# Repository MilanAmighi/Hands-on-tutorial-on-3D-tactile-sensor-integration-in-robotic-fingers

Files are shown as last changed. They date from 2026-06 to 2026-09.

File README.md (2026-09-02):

# 🤖 Hands-on Tutorial: 3D Tactile Sensor Integration in Robotic Fingers for Smart Manipulation

**Hands-on Tutorial presented at ICRA 2026**

**Organisers of the event:** Milan Amighi, Constantin Scholz, and Bram Vanderborght  
*(Brubotics – VUB & imec, in collaboration with Melexis)*

---

## 🧠 Overview

Despite skin being our largest sensory organ, touch remains underused in robotics. Tactile sensing is vital for safe and dexterous manipulation, human-robot interaction, and wearable devices, yet most robotic sensors measure only normal pressure. We live among materials with distinct rigidity, friction, weight, and texture, differences that humans intuitively perceive through touch. Robots can already move, see, and hear; the next frontier is enabling them to truly *feel*, so they can grasp delicate and deformable objects while accounting for each object's physical properties.

This hands-on tutorial introduces an affordable, compact, and robust 3D tactile sensor developed by Melexis: the **Tactaxis® 3D force sensor**, which uses automotive-grade Hall-effect technology to measure both normal and shear forces simultaneously.

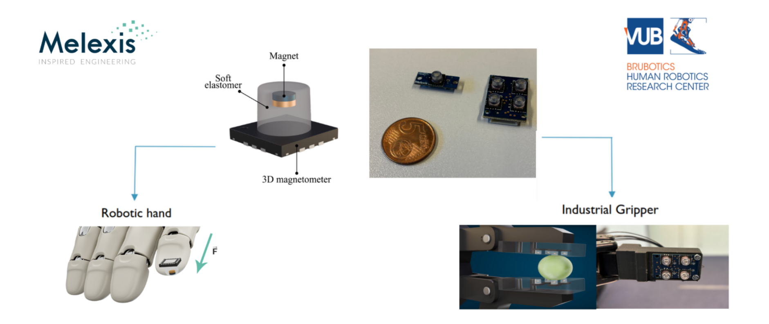
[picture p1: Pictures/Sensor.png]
Melexis Tactaxis 3D Force Sensor


<p align="center">
  Touch sensor demo
</p>

This tutorial allows the user to:
- 🔩 Assemble a two-finger gripper ([PincOpen from Pollen Robotics](https://pollen-robotics.github.io/PincOpen/))
- 🖐️ Integrate the Tactaxis® sensor into the fingertips
- 🚀 Deploy the full system on a real robotic manipulation task

Through guided experiments, you will map force signals to interaction dynamics, detect slip, and implement adaptive grasp control that responds to the properties of the object being handled. You will leave with practical know-how, open-source resources, and a grounded understanding of why touch enables safer, more precise, and more versatile robot behavior.

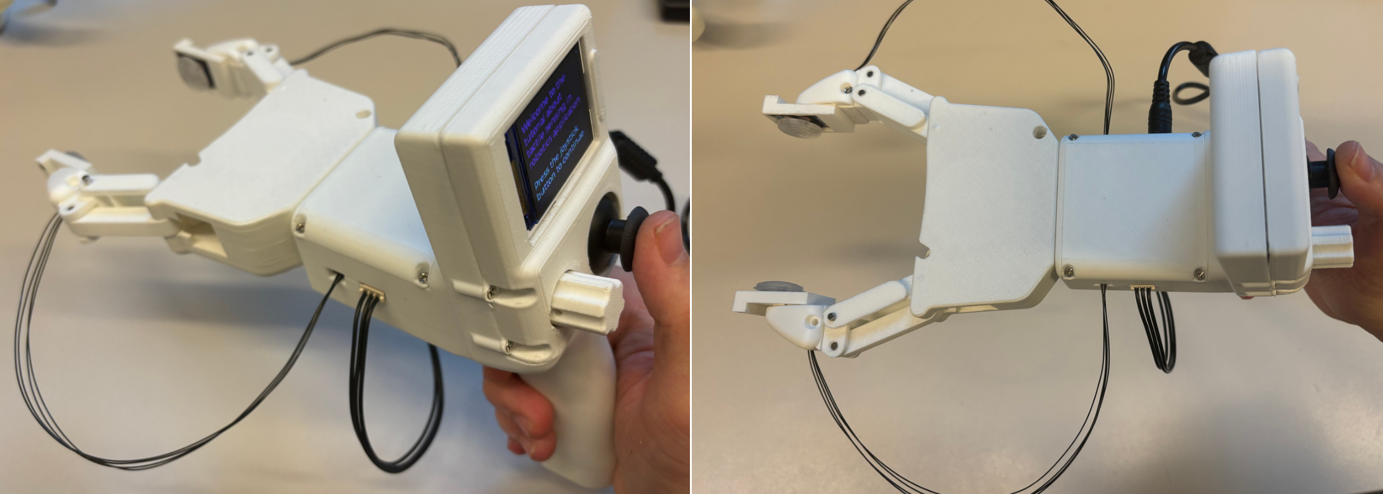
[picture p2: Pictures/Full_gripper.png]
Full gripper overview


**Small video of workshop/tutorial presented at ICRA2026:** [▶️ Watch on YouTube](https://www.youtube.com/watch?v=7zQnEL_h0f4)

**Concept demonstration on a Robotiq 2F-85 gripper(ITF 2025 with imec):** [▶️ Watch on YouTube](https://www.youtube.com/watch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)

---

## 📁 Repository Structure

```
.
├── Gripper-BOM.xlsx                  # Bill of materials: electronics, fasteners, and parts needed to build the gripper, with purchase links
├── Gripper Kit - Assembly guide.pdf  # Step-by-step assembly guide for the full gripper
├── Electronics/                      # Circuit diagrams and electronics documentation
├── Design/                           # STEP and STL files for 3D printing, incl. the moulds for the PDMS sensor cover
├── Docker/                           # Dockerfile and scripts to create a containerised ROS 2 environment
├── Codes/                            # ROS 2 packages, python only and motor initialisation scripts
├── pyproject.toml                    # Pixi environment (ROS 2 via RoboStack) + Python dependencies + `pixi run` tasks
├── pixi.lock                         # Reproducible Pixi environment
├── requirements.txt                  # Minimal pip dependencies for the Python-only scripts
```

---

## ✅ Prerequisites

- Basic familiarity with ROS 2 and Python is helpful but not required
- One of the three environments below (Pixi, Docker, or a manual install) installed on your laptop
- All hardware kits (3D-printed parts, fasteners, sensors) will be provided on-site

---

## 🏁 Getting Started

> The following code has been tested on Ubuntu 22.04. A Dockerfile and Pixi environment are also provided to automatically install all required libraries, depending on the OS used by the user. 

### Step 1 — Clone the repository

```bash
git clone https://github.com/MilanAmighi/Hands-on-tutorial-on-3D-tactile-sensor-integration-in-robotic-fingers.git
cd Hands-on-tutorial-on-3D-tactile-sensor-integration-in-robotic-fingers
```

> ⚠️ **Windows users — long paths warning.** This repository contains deeply nested files. You **must** enable long paths in Git *before* cloning, or your checkout will fail:
>
> ```bash
> git config --global core.longpaths true
> ```

### Step 2 — Assemble the gripper

Follow `Gripper Kit - Assembly guide.pdf` to build the complete gripper. The list of material is in `Gripper-BOM.xlsx`, all the CAD design in the folder `Design` and the PCB schematics in the folder `Electronics`.

### Step 3 — Install your software environment

Three options are provided. **You only need one of them**; pick the one matching your operating system and preference:

| Option | Best for | OS | ROS 2 included | 
|---|---|---|---|
| **A. 🧪 Pixi** *(recommended)* | Everyone, especially MacOS and Windows | MacOS (Intel & Apple Silicon), Linux, Windows | ✅ Humble via RoboStack | 
| **B. 🐳 Docker** | Linux users who prefer containers | Ubuntu 22.04 (tested) | ✅ Humble | 
| **C. 🐍 Manual install** | Quick sensor tests without ROS 2 | Windows, Linux, MacOS | ❌ (install it yourself) | 

---

## 🧪 Option A — Pixi

[Pixi](https://pixi.prefix.dev/latest/) automatically manages ROS 2 and Python dependencies locally on **Windows, Linux and MacOS**, without needing a full virtual machine or a Docker container. ROS 2 Humble comes from [RoboStack](https://robostack.github.io) and everything is pinned in `pixi.lock`, so every participant gets the exact same environment.

**A.1 — Install Pixi** (if you haven't already):

- Windows (PowerShell):
  ```powershell
  iwr -useb https://pixi.sh/install.ps1 | iex
  ```
- Linux/MacOS (Bash):
  ```bash
  curl -fsSL https://pixi.sh/install.sh | bash
  ```

Restart your terminal after installing, then verify:

```bash
pixi --version
```

**A.2 — Set up the environment**, from the root of the repository:

```bash
cd Hands-on-tutorial-on-3D-tactile-sensor-integration-in-robotic-fingers
pixi install  # Downloads all ROS 2 and Python dependencies
pixi shell    # Activates the isolated environment
```

The first `pixi install` downloads ROS 2 Humble and all Python dependencies into a local `.pixi/` folder and can take several minutes.

**A.3 — Build the workspace:**

```bash
pixi run build
```

**A.4 — Run tasks.** List them with:

```bash
pixi task list
```

Then run one with:

```bash
pixi run <name-of-the-task>
```

Multible task and codes are available in `/Hands-on-tutorial-on-3D-tactile-sensor-integration-in-robotic-fingers/Codes`.

---

## 🐳 Option B — Docker

The Dockerfile builds an Ubuntu 22.04 image with ROS 2 Humble and all Python dependencies pre-installed. Tested on Ubuntu 22.04 hosts.

> ⚠️ **Plug the USB-C cable in before starting the container.** Serial devices are mapped at container start; a cable plugged in afterwards will not be visible inside the container.

**B.1 — Install Docker** ([official guide](https://docs.docker.com/engine/install/)) and allow your user to run it:

```bash
sudo usermod -aG docker $USER    # then log out and back in
docker run hello-world
```

**B.2 — Build the image and start the container**, from the `Docker/` folder. **Before starting the Docker container**, connect the USB-C cable from the gripper to your computer:

```bash
cd Docker
./buildrun.sh
```

`buildrun.sh` runs `build.sh` (builds the `docker3dsensors` image) followed by `run.sh` (starts the container with the serial devices, USB bus and X11 display forwarded, and the repository mounted at `/Hands-on-tutorial-on-3D-tactile-sensor-integration-in-robotic-fingers`).

**B.3 — Open extra terminals** in the *same running* container (some demos need two):

```bash
docker exec -it docker3dsensors bash
```

**B.4 — Build the ROS 2 workspace**, inside the container:

```bash
cd /Hands-on-tutorial-on-3D-tactile-sensor-integration-in-robotic-fingers/Codes/ros2_ws
colcon build
source install/setup.bash
```

---

## 🐍 Option C — Manual/native install

Use this if you only want the Python scripts without ROS 2.

**C.1 — Install Python 3** (3.12 or newer recommended).

**C.2 — Install the Python dependencies**, from the root of the repository:

```bash
pip install -r requirements.txt
```

`requirements.txt` contains `numpy`, `pyserial`, `crc` and `esptool` — enough for `flash.py`, `Motor_initialisation.py`, `simple_connected_mode.py` and `BurstMode.py`.

**C.3 — (Optional) Install ROS 2 Humble yourself** if you also want the ROS 2 nodes, via the [official installation guide](https://docs.ros.org/en/humble/Installation.html), then build the workspace:

```bash
cd Codes/ros2_ws
colcon build
source install/setup.bash
```

> On Windows, replace `/` with `\` in the paths and use `python` instead of `python3`.

---

## ▶️ Next: running the code

Once your environment is installed and the gripper is assembled, connect the ESP32-S3 by USB-C, set the gripper LCD to **Connected** mode, and follow [`Codes/README.md`](Codes/README.md). It covers, for each of the three environments:

- 🔥 flashing the ESP32 firmware,
- ⚙️ initialising the motor before mounting it on the gripper,
- 🕹️ the gripper operating modes (independent, connected, view forces),
- 📡 the Python-only scripts and the ROS 2 demos (tactile visualisation, full system + RViz, PID force control),
- 💾 the CSV recording format and the ROS 2 topic list.

---

## 🙏 Acknowledgements

This project was made possible with the support of **VLAIO** under the Skinaxis project and the **euRobin EU project**. We would also like to sincerely thank:
- **Melexis**, for making this tutorial possible by providing the Tactaxis® sensors
- **ICRA organisers**, for the opportunity to present to the robotics community
- **Pollen Robotics**, for supporting the project with the PincOpen gripper platform

---

## 📬 Contact

| Organisation | Contact |
|---|---|
| Brubotics (VUB & imec) | [Milan.Francois.T.Amighi@vub.be](mailto:Milan.Francois.T.Amighi@vub.be) |
| Melexis | [tls@melexis.com](mailto:tls@melexis.com) |

---

## 📚 References

- T. Le Signor, N. Dupré and G. F. Close, "A Gradiometric Magnetic Force Sensor Immune to Stray Magnetic Fields for Robotic Hands and Grippers," *IEEE Robotics and Automation Letters*, vol. 7, no. 2, pp. 3070–3076, April 2022. [doi:10.1109/LRA.2022.3146507](https://doi.org/10.1109/LRA.2022.3146507)

- T. Le Signor, N. Dupré, J. Didden, E. Lomakin, G. Close, "Mass-Manufacturable 3D Magnetic Force Sensor for Robotic Grasping and Slip Detection," *Sensors*, 23, 3031, 2023. [doi:10.3390/s23063031](https://doi.org/10.3390/s23063031)

- PincOpen Gripper — Pollen Robotics: [https://pollen-robotics.github.io/PincOpen/](https://pollen-robotics.github.io/PincOpen/)

- Fischer, T., Vollprecht, W., Traversaro, S., Yen, S., Herrero, C., & Milford, M. (2021). A RoboStack Tutorial: Using the Robot Operating System Alongside the Conda and Jupyter Data Science Ecosystems. *IEEE Robotics and Automation Magazine*, 28(2). https://doi.org/10.1109/MRA.2021.3128367

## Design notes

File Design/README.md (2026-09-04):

# 🛠️ Design Files

This folder contains all STEP and STL files needed to 3D print and assemble the gripper used in this tutorial. Files are organised into two subfolders:

- 📐 **`step/`** — STEP files for editing or importing into CAD software
- 🧩 **`stl/`** — STL files ready for slicing and printing

---

## 🖨️ Printing Settings

All parts were printed using a **Bambu Lab H2D** printer with the following settings:

| Parameter | Value |
|---|---|
| Infill | 20% |
| Material | PLA (recommended) |

---

## 🧱 Components

### 📦 From the PincOpen Repository (unmodified)

These parts are sourced directly from the [Pollen Robotics PincOpen repository](https://github.com/pollen-robotics/PincOpen/tree/main/cad). Download them there, they are not duplicated here.

| Part | Quantity |
|---|---|
| Internal Rod | 2 |
| External Rod | 2 |
| Distal Rod | 2 |
| Top Plate | 1 |
| Motor Flange | 1 |
| Cam | 1 |
| Driving Rod | 2 |
| Bottom Plate | 1 |

---

### 🔧 Modified from PincOpen (adapted for Tactaxis® sensor integration)

These parts originate from the PincOpen design but have been modified to accommodate the Melexis Tactaxis® 3D force sensors in the fingertips.

| Part | Quantity |
|---|---|
| Removable Tip | 2 |
| Distal Shell | 2 |

---

### ✨ New Components (added for electronics integration)

These parts are fully original additions to the design, providing housing for the PCB and control electronics.

| Part | Quantity |
|---|---|
| Head Housing | 1 |
| Interface Panel for Head Housing | 1 |
| Top Panel for Head Housing | 1 |
| Potentiometer Knob | 1 |

---

### 🎯 Sensor Reference Model

A reference STEP and STL of the Tactaxis® sensor body is included for alignment and integration purposes.

| Part | Quantity |
|---|---|
| Tactaxis Sensor | 2 |

---

### 🫧 PDMS Sensor Cover (moulded)

A soft silicone cover sits on top of each Tactaxis® sensor to **distribute the contact force more evenly across the four taxels**, instead of letting a point contact load a single taxel. It is not 3D printed: it is cast in a two-part mould, which is printed.

| Part | Quantity | File |
|---|---|---|
| Tactaxis PDMS Cover *(cast, reference geometry)* | 2 | `stl/Tactaxis_PDMS_Cover.STL` · `step/Tactaxis_PDMS_Cover.STEP` |
| Cover Mould — Bottom | 1 | `stl/Tactaxis_PDMS_Cover_Mold_Bottom.STL` · `step/…_Mold_Bottom.STEP` |
| Cover Mould — Top | 1 | `stl/Tactaxis_PDMS_Cover_Mold_Top.STL` · `step/…_Mold_Top.STEP` |

**Material:** the covers are cast in **SYLGARD™ 182 Silicone Elastomer** from Dow, a two-part PDMS with a hardness of **Shore 43A**. Only the two mould halves are 3D printed; the `Tactaxis_PDMS_Cover` file itself is the resulting part geometry, provided as a reference for CAD and for checking the fit in the fingertip.

---

## 📡 Tactaxis® Sensor — Info & Dimensions

The **Melexis Tactaxis® 3D force sensor** is a compact, automotive-grade Hall-effect sensor that simultaneously measures normal (Fz) and shear (Fx, Fy) forces. It is designed for integration into robotic fingertips where space and robustness are critical.

| Dimensions | Value |
|---|---|
| Surface | ~24 mm × 18 mm |
| Overall assembly height | ~6 mm (sensor + magnet housing) |
| Number of taxels per sensor | 4 |

> The sensor snaps into the **Removable Tip** cavity. The STEP file `step/Tactaxis_Sensor.STEP` represents the sensor body and can be used as a reference when adapting the fingertip geometry.

---

## 📝 Notes

- The STEP files can be opened and modified in any CAD software (e.g. FreeCAD, Fusion 360, SolidWorks, OnShape).
- If you want to adapt the fingertip design for a different sensor, the **Removable Tip** and **Distal Shell** STEP files are the relevant starting points.
- For the full bill of materials including fasteners and electronics, refer to `BOM.xlsx` at the root of the repository.

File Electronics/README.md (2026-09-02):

# Electronics folder
Folder containing circuit diagrams and electronics documentation.

# ⚡ Electronics & Firmware
Welcome to the electronics section of the Tactile Sensor Gripper ! This folder contains everything you need to build the electronic circuit, understand the high-level firmware, and flash the code to your ESP32.

## 📋 Table of Contents
- [⚡ Electronics \& Firmware](#-electronics--firmware)
  - [📋 Table of Contents](#-table-of-contents)
  - [🔬 Overview](#-overview)
  - [🛠️ Hardware](#️-hardware)
    - [Bill of Materials (BOM)](#bill-of-materials-bom)
    - [Schematics](#schematics)
  - [🧠 Firmware Architecture](#-firmware-architecture)
    - [Mode 0 — Independent](#mode-0--independent)
    - [Mode 1 — Connected](#mode-1--connected)
    - [Serial Frame Protocol](#serial-frame-protocol)
      - [Frame structure](#frame-structure)
      - [Commands (PC → ESP32)](#commands-pc--esp32)
      - [Response (ESP32 → PC)](#response-esp32--pc)
      - [Burst frame payload (`0x15`) — 126 bytes total](#burst-frame-payload-0x15--126-bytes-total)
    - [Mode 2 — View Forces](#mode-2--view-forces)
  - [💻 Flashing the ESP32](#-flashing-the-esp32)
    - [Prerequisites](#prerequisites)
    - [Step-by-Step Guide](#step-by-step-guide)

---

## 🔬 Overview
This section is powered by an ESP32 microcontroller, which handles the data acquisition from the tactile sensors, computes the 3d force and interfaces with the peripherals.

> 📦 **Firmware source is not (yet) published in this repository.** Only the pre-built binary is included (see [Flashing the ESP32](#-flashing-the-esp32)) — the sections below describe the firmware's architecture and protocol for reference, but there is no `.c`/`.cpp` source to build or modify here. You can reflash the same provided binary, but cannot currently recompile or change the firmware yourself.

---

## 🛠️ Hardware
The electronics for this tutorial are split across two custom printed circuit boards.
- Gripper Controller: This is the main board. It hosts the ESP32 microcontroller, the core tactile sensors, and the motor driver required to operate the gripper.
- User Interface: This secondary board is designed for manual interaction. It hosts an LCD screen, a potentiometer, and a joystick, allowing users to control the gripper and visualize data directly without needing a computer.

### Schematics

| Gripper Controller | User Interface |
| :---: | :---: |
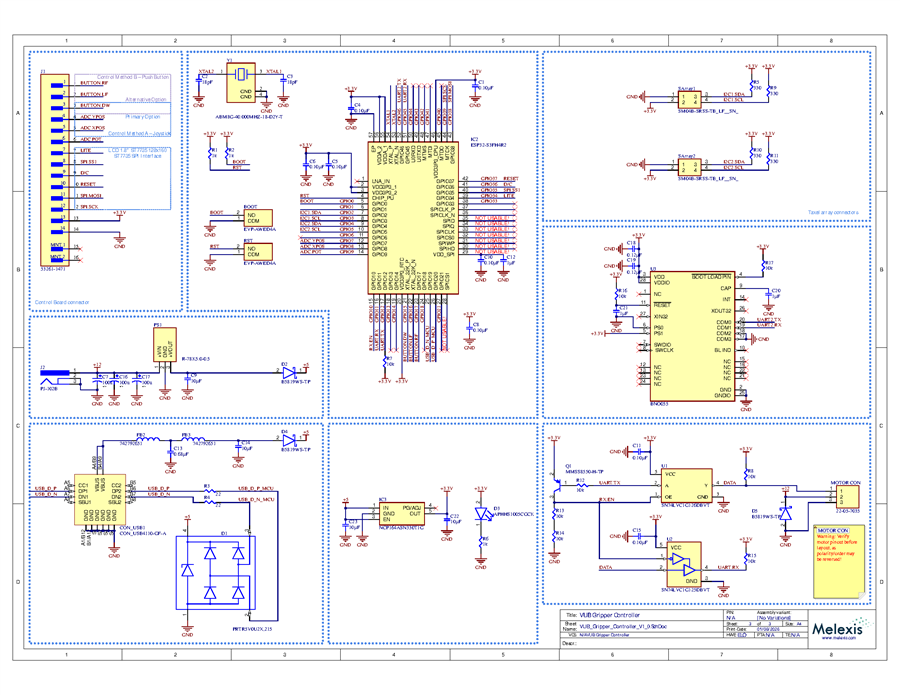
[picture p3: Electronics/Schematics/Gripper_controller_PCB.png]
Gripper Controller schematic
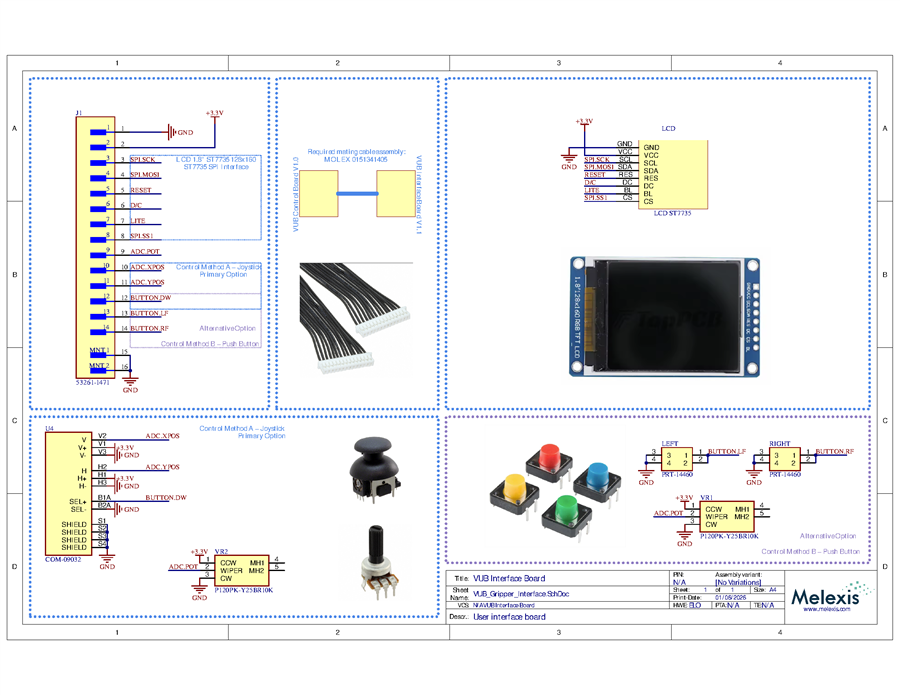
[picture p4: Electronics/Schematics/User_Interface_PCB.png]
User Interface schematic
|  |  |
| 📄 [Open full PDF](./Schematics/Gripper_controller_PCB.pdf) | 📄 [Open full PDF](./Schematics/User_Interface_PCB.pdf) |

### Bill of Materials (BOM)

#### Gripper Controller

| Part number | Description | Designator | Qty |
| :--- | :--- | :--- | :---: |
| EVP-AWED4A | Switch | BOOT, RST | 2 |
| GCM155R71C104KA55D | CAP CER 0.1 µF 16 V X7R 0402 | C1, C4, C5, C6, C8, C10, C11, C15 | 8 |
| GCM1555C1H180JA16D | CAP CER 18 pF 50 V NP0 0402 | C2, C3 | 2 |
| EEEFK1C101P | Aluminum Electrolytic 100 µF 16 V 5.3×5.8 mm | C7, C16, C17 | 3 |
| GRJ155R60J106ME11D | CAP CER 10 µF 6.3 V X5R 0402 | C9, C14, C22, C23 | 4 |
| GCM188R71C105KA64D | CAP CER 1 µF 16 V X7R 0603 | C12, C20, C21 | 3 |
| GRM155R60J684KE19D | CAP CER 0.68 µF 6.3 V X5R 0402 | C13 | 1 |
| GRM188R61A124KA01D | CAP CER 0.12 µF 10 V X5R 0603 | C18, C19 | 2 |
| USB4110-GF-A | USB Type-C receptacle, SMD right-angle | CON_USB1 | 1 |
| PRTR5V0U2X,215 | TVS diode 5.5 V SOT143B | D1 | 1 |
| B5819WS-TP | Schottky diode 40 V 1 A SOD323 | D2, D4, D5 | 3 |
| APHHS1005CGCK | LED green clear chip SMD | D3 | 1 |
| 742792651 | Ferrite bead 600 Ω 0603 | FB2, FB3 | 2 |
| ESP32-S3FH4R2 | RF transceiver + MCU BLE 56-QFN | IC2 | 1 |
| NCP164ASN330T1G | LDO regulator 3.3 V 300 mA 5-TSOP | IC3 | 1 |
| 53261-1471 | Connector header SMD R/A 14-pos 1.25 mm | J1 | 1 |
| PJ-102B | DC power jack through-hole R/A 2.5 mm | J2 | 1 |
| 22-05-7035 | Connector header R/A 3-pos 2.5 mm Molex | MOTOR CON | 1 |
| R-78K5.0-0.5 | DC/DC converter 5 V 0.5 A | PS1 | 1 |
| MMSS8550-H-TP | Transistor PNP 25 V 1.5 A SOT-23 | Q1 | 1 |
| ERJ-2GEJ102X | RES SMD 1 kΩ 5% 1/10 W 0402 | R1, R2, R6 | 3 |
| ERJ-2RKF22R0X | RES SMD 22 Ω 1% 1/10 W 0402 | R3, R4 | 2 |
| ERJ-2RKF3300X | RES SMD 330 Ω 1% 1/10 W 0402 | R5, R9, R10, R11 | 4 |
| ERJ-2GEJ103X | RES SMD 10 kΩ 5% 1/10 W 0402 | R7, R8, R12–R17 | 8 |
| SM04B-SRSS-TB | Connector header SMD R/A 4-pos 1 mm | SArray1, SArray2 | 2 |
| SN74LVC1G126DBVT | Buffer non-inverting 5.5 V SOT23-5 | U1 | 1 |
| SN74LVC1G125DBVT | Buffer non-inverting 5.5 V SOT23-5 | U2 | 1 |
| BNO055 | IMU accel/gyro/mag I2C 28-LGA | U3 | 1 |
| ABM8G-40.000MHZ-18-D2Y-T | Crystal 40 MHz 18 pF SMD | Y1 | 1 |

#### User Interface

| Part number | Description | Designator | Qty |
| :--- | :--- | :--- | :---: |
| 53261-1471 | Connector header SMD R/A 14-pos 1.25 mm | J1 | 1 |
| LCD ST7735 | LCD 1.8″ ST7735 | LCD | 1 |
| PRT-14460 | Tactile switch | LEFT, RIGHT | 2 |
| COM-09032 | Thumb joystick | U4 | 1 |
| P120PK-Y25BR10K | Potentiometer 10 kΩ | VR1, VR2 | 2 |

---

## 🧠 Firmware Architecture

The ESP32-S3 firmware runs on **FreeRTOS** and is structured around a top-level **state machine**. On boot, the LCD displays a welcome screen — press the joystick button to reach the mode-selection menu, then tilt the joystick up/down to highlight a mode and press to confirm.

```text
Boot
 └─► Welcome screen  (press joystick to continue)
      └─► Mode Selection Menu
           ├─► [0] Independent  ──► Manual sub-mode  (joystick → motor position)
           │                    └─► Adaptive sub-mode (potentiometer → target force, on-board PD controller)
           ├─► [1] Connected    ──► Streams sensor data to PC over USB-C; accepts motor commands
           └─► [2] View Forces  ──► Live Fx/Fy/Fz display on LCD only
```

---

### Mode 0 — Independent

No computer required; the gripper operates fully standalone.

| Sub-mode | How to interact | What happens |
| :--- | :--- | :--- |
| **Manual** | Tilt joystick to open/close gripper | Motor position follows joystick; live Fx/Fy/Fz from both fingers shown on LCD |
| **Adaptive** | Turn potentiometer to set target force; tilt joystick to select object type | On-board PD controller adjusts motor to maintain the target grasp force; gains switch automatically for the selected object (cube / sponge / cup) |
| **Reset** | Press joystick | Returns to the main menu |

> **Tutorial use:** start here to verify the hardware is working and to get a feel for the force feedback before connecting to the computer.

---

### Mode 1 — Connected

The gripper waits for commands from the host PC over the USB-C serial link (CDC).

**What the firmware streams to the PC :**

| Data | refresh rate | Description |
| :--- | :--- | :--- |
| Force frames | up to ~500 Hz | 8 sensors × Fx, Fy, Fz (4 sensors per finger) |
| IMU | 20 Hz | BNO055 gravity vector (linear acceleration) |
| Joystick | 20 Hz | X/Y axes + button state |
| Potentiometer | 20 Hz | Raw ADC value (0–4095) |
| Motor position | 20 Hz | Current STS3215 servo position |

**What the firmware accepts from the PC:**

| Command | Effect |
| :--- | :--- |
| Motor drive | Sets motor position, speed, and acceleration |
| Start/stop burst | Enables or disables sensor streaming |
| Configure rates | Changes the streaming period for each data type |

> **Tutorial use:** select this mode before launching any Python script or ROS 2 node. The scripts will not receive data if the gripper is in a different mode.

---

### Serial Frame Protocol

All traffic between the PC and the ESP32 uses the same framing layer in both directions.

#### Frame structure

```text
┌──────────┬────────┬──────────┬──────────────────┬──────────┬────────┐
│ START    │ ID     │ LEN      │ PAYLOAD          │ CRC-8    │ END    │
│ 0x7E (1B)│ (1B)   │ (1B)     │ (LEN bytes)      │ (1B)     │ 0x7F   │
└──────────┴────────┴──────────┴──────────────────┴──────────┴────────┘
```

- **CRC-8** covers `[ID, LEN, PAYLOAD...]` (computed before byte stuffing) — for the burst frame (`0x15`) that is `1 (ID) + 1 (LEN) + 126 (PAYLOAD)` = **128 bytes** fed into the CRC-8.
- **Byte stuffing** — any occurrence of a special byte inside `[ID … CRC-8]` is replaced with an escape sequence:

| Original byte | Escaped sequence |
| :--- | :--- |
| `0x7E` (START) | `0x7D 0x5E` |
| `0x7F` (END) | `0x7D 0x5F` |
| `0x7D` (ESC) | `0x7D 0x5D` |

To decode: after receiving `0x7D`, XOR the next byte with `0x20` to recover the original value.

---

#### Commands (PC → ESP32)

| ID | Name | Payload |
| :--- | :--- | :--- |
| `0x14` | `STREAM_BURST` | 16-byte config — starts the high-rate burst stream |
| `0x1F` | `STREAM_STOP` | *(none)* — stops the active stream |
| `0x40` | `MOTOR_CONTROL` | `position` int16 + `speed` uint16 + `acc` uint8 (all LE) |

#### Response (ESP32 → PC)

| ID | Name | Payload |
| :--- | :--- | :--- |
| `0x15` | `STREAM_BURST` | see burst frame layout below |

---

#### Burst frame payload (`0x15`) — 126 bytes total

```text
Offset  Size  Type          Field
──────  ────  ────────────  ──────────────────────────────────────────────
  0     96    8 × {f32,     force[0..7].{Fx, Fy, Fz}  (Newton)
               f32, f32}    sensors 0–3 = left finger (I2C bus 0)
                             sensors 4–7 = right finger (I2C bus 1)
 96      2    int16 LE      gravity_x_lsb  (BNO055 raw LSB)
 98      2    int16 LE      gravity_y_lsb
100      2    int16 LE      gravity_z_lsb
102      2    uint16 LE     imu_success_count
104      2    uint16 LE     imu_fail_count
106      2    uint16 LE     force_success_count
108      2    uint16 LE     force_fail_count
110      2    int16 LE      imu_last_err  (ESP-IDF error code)
112      1    uint8         imu_last_read_ok  (1 = OK, 0 = fail)
113      1    uint8         force_last_read_ok
114      2    int16 LE      joystick_x
116      2    int16 LE      joystick_y
118      1    uint8         joystick_button  (1 = pressed)
119      1    uint8         _pad
120      2    int16 LE      potentiometer  (0–4095)
122      4    int32 LE      motor_position
```

**Byte-count check** — add up the fields yourself to confirm the 126 bytes:

| Group | Fields | Bytes |
| :--- | :--- | ---: |
| Forces | 8 sensors × 3 axes × `f32` (4 B) | 8 × 3 × 4 = **96** |
| Gravity | `gravity_x/y/z_lsb`, 3 × `int16` | 3 × 2 = **6** |
| IMU/force health counters | `imu_success_count`, `imu_fail_count`, `force_success_count`, `force_fail_count`, 4 × `uint16` | 4 × 2 = **8** |
| IMU last error | `imu_last_err`, `int16` | **2** |
| Health flags | `imu_last_read_ok`, `force_last_read_ok`, 2 × `uint8` | 2 × 1 = **2** |
| Joystick | `joystick_x`, `joystick_y` (`int16` each) + `joystick_button` + `_pad` (`uint8` each) | 2×2 + 2×1 = **6** |
| Potentiometer | `potentiometer`, `int16` | **2** |
| Motor position | `motor_position`, `int32` | **4** |
| **Total payload** | | **96+6+8+2+2+6+2+4 = 126** |

So the full unstuffed frame on the wire for a burst response is `START(1) + ID(1) + LEN(1) + PAYLOAD(126) + CRC-8(1) + END(1)` = **131 bytes** (before any byte stuffing, which can add extra bytes if `0x7E`/`0x7F`/`0x7D` appear inside `[ID … CRC-8]`).

---

### Mode 2 — View Forces

Displays live Fx, Fy, Fz and contact detection for both fingers directly on the LCD. No computer needed. Press the joystick button to return to the main menu.

---

## 💻 Flashing the ESP32

The pre-built firmware binaries are included in the repository under `Codes/python_codes/flash/bin/`. A small Python helper script handles the entire flashing process — no ESP-IDF installation required.

> ℹ️ The firmware **source code is not included** in this repository — only the compiled binaries needed to flash the board. This lets you get the gripper running for the tutorial, but there is nothing to inspect or modify beyond what's documented in [Firmware Architecture](#-firmware-architecture) above.

### Prerequisites

- Python 3.8 or later
- `esptool` Python package:

  ```bash
  pip install esptool
  ```

  > The script also searches for an existing ESP-IDF Python environment under `~/.espressif/` and will use it automatically if found.

- A USB-C cable connecting the ESP32-S3 to your computer (native USB port on the board, **not** the UART port if your board has both).

### Step-by-Step Guide

1. **Connect** the ESP32-S3 to your computer via USB-C and wait for the OS to enumerate the device.

   On Linux/macOS, verify the port appeared:

   ```bash
   ls /dev/ttyACM* /dev/ttyUSB*
   ```

   On Windows, check **Device Manager → Ports (COM & LPT)** for a new `COMx` entry.

2. **Navigate** to the flash directory:

   ```bash
   cd Codes/python_codes/flash
   ```

3. **Run** the flash script:

   ```bash
   python flash.py
   ```

   The script auto-detects the ESP32-S3 by USB VID/PID (`0x303A / 0x1001`). If more than one device is connected, or auto-detection fails, pass the port explicitly:

   ```bash
   # Linux / macOS
   python flash.py -p /dev/ttyACM0

   # Windows
   python flash.py -p COM9
   ```

   Optional arguments:

   | Flag | Default | Description |
   | :--- | :--- | :--- |
   | `-p`, `--port` | auto-detect | Serial port of the ESP32-S3 |
   | `--baud` | `460800` | Flash baud rate |

4. **Wait** for the script to finish. It flashes the bootloader, partition table, and main firmware, then hard-resets the board.

5. **Confirm** the board is running: the LCD should show the tutorial welcome screen within a few seconds of the reset.

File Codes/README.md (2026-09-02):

# 🤖 Codes

This folder contains all the software for the tutorial: a ROS 2 package (`ros2_tactile_robot`) and standalone Python scripts. The ROS 2 stack runs on **ROS 2 Humble**, either through the Pixi environment or inside the provided Docker container; the Python-only scripts can also be run directly on the host.

> 📌 Install your environment first — see [Step 3 of the main README](../README.md#step-3--install-your-software-environment) (Pixi, Docker or manual install).

---

## 📁 Repository Structure

```
Codes/
├── record_data/                     # CSV files saved by the GUI tools
├── python_codes/
│   ├── BurstMode.py                 # Standalone live GUI: force bars, joystick, pot, IMU + CSV recording
│   ├── Motor_initialisation.py      # Standalone script to initialise motor position before attaching it to the gripper
│   ├── simple_connected_mode.py     # Minimal connected-mode example (no GUI)
│   ├── SerialLibrary/               # Low-level ESP32 serial communication library
│   └── flash/                       # Firmware flashing utility (esptool-based)
│       └── flash.py
└── ros2_ws/
    └── src/
        └── ros2_tactile_robot/
            ├── launch/
            │   ├── full_system.launch.py       # All nodes: sensor, motor, GUI, joystick, pot, RViz
            │   └── pid_force_control.launch.py # PID force control + real-time force plot
            ├── meshes/                         # STL files for RViz finger visualisation
            ├── rviz/
            │   └── tactile_viz.rviz            # Pre-configured RViz scene
            └── ros2_tactile_robot/
                ├── esp_bridge_node.py          # ESP32 hardware interface (serial ↔ ROS 2 topics + RViz wrenches)
                ├── sensor_node.py              # Force magnitude & contact detection
                ├── motor_node.py               # Motor command arbitration
                ├── pid_control_node.py         # Adaptive PID force controller
                ├── joystick_node.py            # Joystick → velocity / motor commands
                ├── potentiometer_node.py       # Potentiometer → motor position setpoint
                ├── lcd_node.py                 # LCD display driver
                ├── gui_node.py                 # Desktop GUI: live force bars, joystick, pot, IMU + CSV recording
                ├── pid_gui_node.py             # Real-time Fg and Fn plot to do PID force control + CSV export
                └── tactile_finger_gui_node.py  # Per-finger tactile map + torque visualisation
```

---

## Forces sensors frame

The following frame has been considered in the codes for touch sensing:

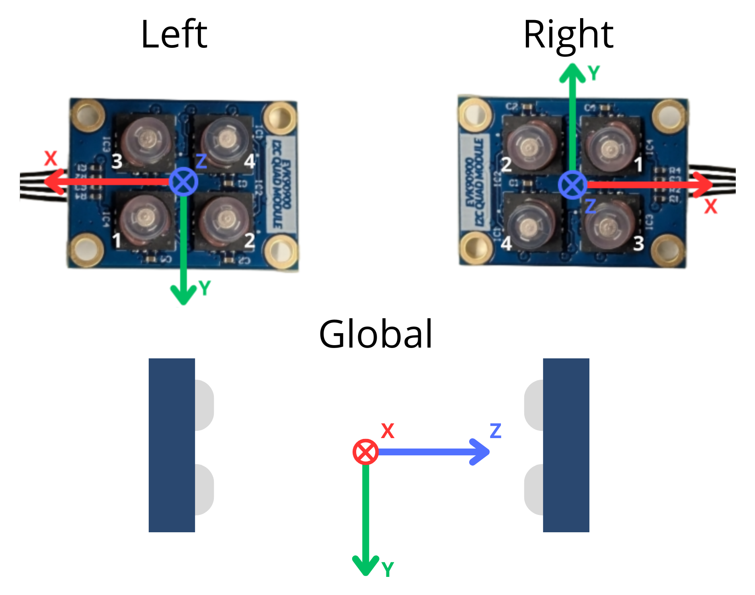
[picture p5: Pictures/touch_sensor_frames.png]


F_g represents the gravitational force component along the gravity vector, as measured by the onboard IMU. F_n is the total normal force exerted on the object; since the two sensors apply equal force through each finger, the sum F_z should ideally be 0 N.

## 🚀 Before starting 
### 🔥 Flash the Firmware 

If the ESP32 has not been flashed yet, run the flashing script (requires `esptool`).

To run it with Pixi:
```bash
pixi run flash
```
To run it with Docker or with native installation:
```bash
cd /Hands-on-tutorial-on-3D-tactile-sensor-integration-in-robotic-fingers/Codes/python_codes/flash

#To launch the code
python3 flash.py
```

### ⚙️ Motor Initialisation
> Make sure the gripper LCD is set to **Connected** mode before running this command (see below)

Run this script first to confirm the serial link is working and bring the motor to its reference position before attaching it to the gripper.

To run it with Pixi:
```bash
pixi run motor
```

To run it with Docker or with native installation:
```bash
cd /Hands-on-tutorial-on-3D-tactile-sensor-integration-in-robotic-fingers/Codes/python_codes

#To launch the code
python3 Motor_initialisation.py
```

> With Pixi, the optional arguments below are passed after `--`, e.g. `pixi run motor -- -p /dev/ttyUSB0`.

Optional arguments:

| Flag | Default | Description |
|---|---|---|
| `-p`, `--com-port` | auto-detect | Serial port of the ESP32 (e.g. `/dev/ttyUSB0`) |
| `-s`, `--speed` | `250` | Motor speed |
| `-a`, `--acc` | `250` | Motor acceleration |
| `-f`, `--burst-frequency` | `200` | Sensor burst frequency in Hz |
| `-g`, `--debug` | off | Print raw serial frames for debugging |

## 🕹️ Gripper Operating Modes

Once the LCD on the gripper is on, the joystick can be used to navigate between modes. From the initial menu, pressing the joystick like a button opens the mode selection menu. The gripper firmware exposes three top-level modes, selectable from the on-board LCD menu: independent, connected and view forces mode.

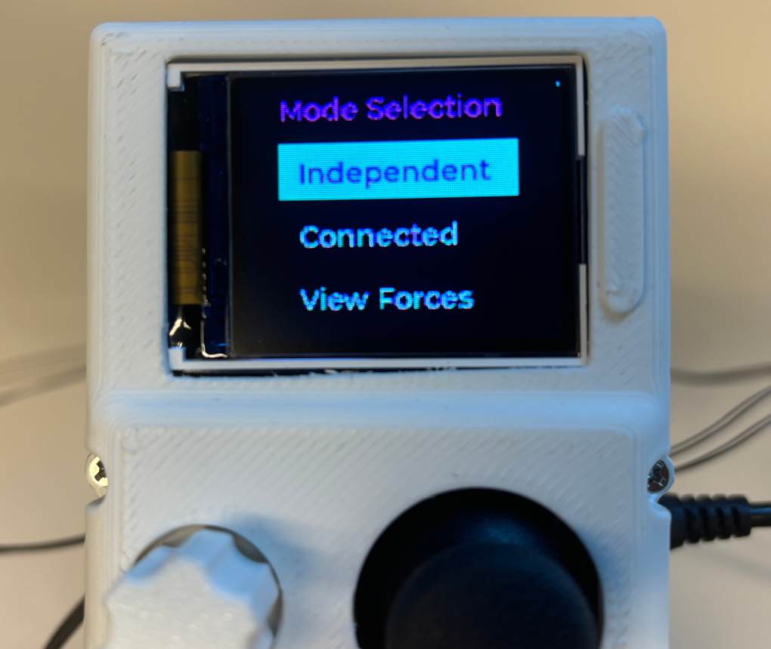
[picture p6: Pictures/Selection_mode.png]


### 1. 🔓 Independent Mode

Requires only the power supply, no USB-C cable to the computer is needed. You will be able to control the gripper thanks to the external PCB, the potentiometer and the joystick. Three sub-options are available:

| Sub-mode | Description |
|---|---|
| **Manual** | Control motor position directly with the joystick. Live normal force Fn and gravity force Fg readings are shown on the LCD. |
| **Adaptive** | Control the target grasp force with the potentiometer. A PD controller tracks the force setpoint; Kp and Kd gains change automatically depending on the selected object type (fragile plastic cup, deformable sponge, rigid wood cube). Use the joystick to switch between objects moving it left or right. |
| **Reset** | Return to the main menu. |

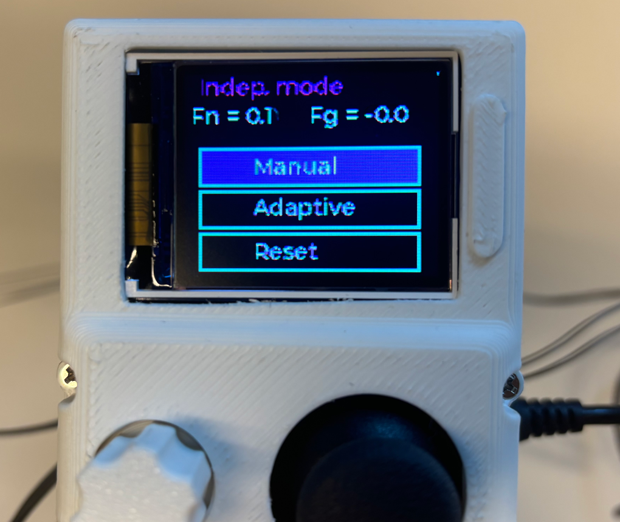
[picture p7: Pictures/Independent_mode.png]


In **Manual** mode, the joystick controls the gripper position while live Fn and Fg readings from the force sensors are displayed on the LCD.

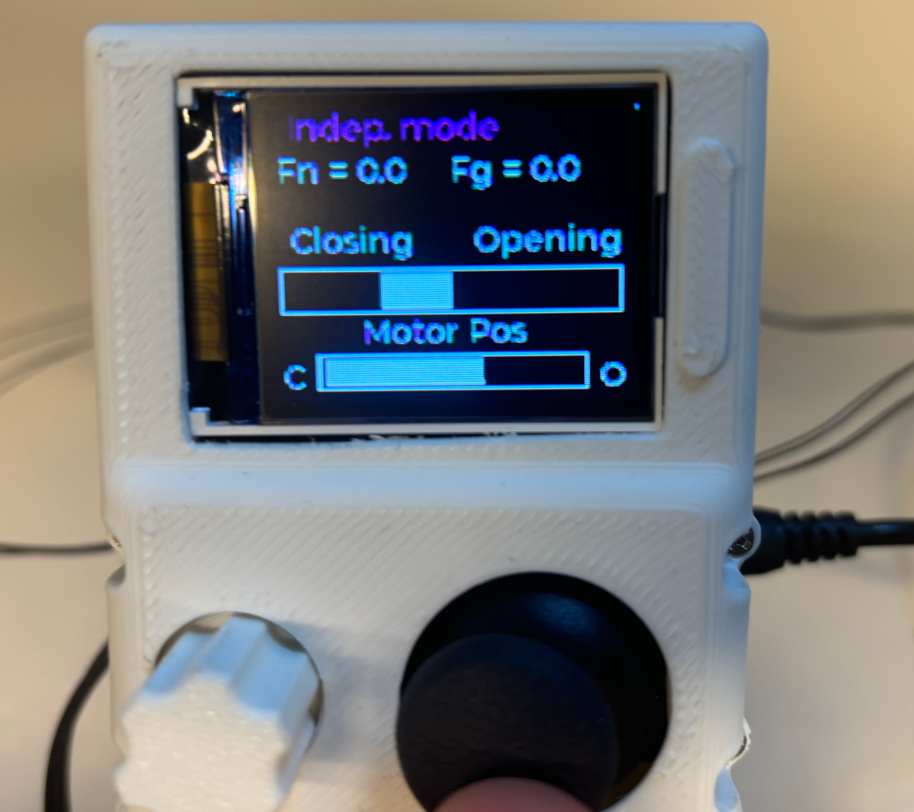
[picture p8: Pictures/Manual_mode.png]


In **Adaptive** mode, the potentiometer sets the target grasp force. The PD controller adjusts the motor position to maintain that force, with gains tuned automatically based on the object selected with the joystick moving it left or right.

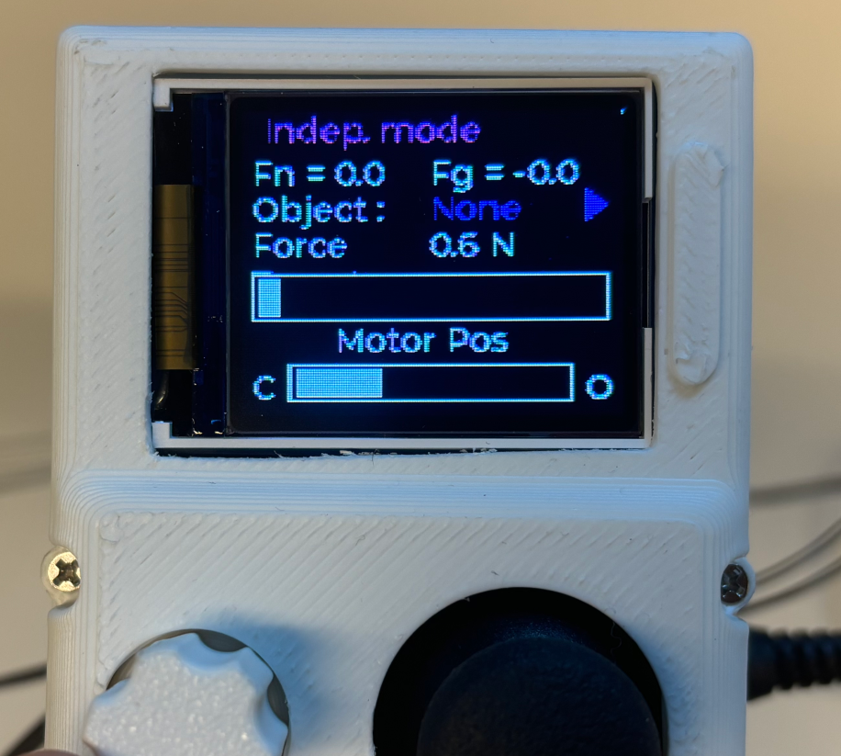
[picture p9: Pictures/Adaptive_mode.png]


### 2. 🔌 Connected Mode

The gripper waits for commands from the computer via USB-C serial. **Select this mode on the LCD before launching any ROS 2 node or Python script. This screen must be visible before any commands or code can be launched from the computer.** After some time, the screen may automatically return to the initial menu. If this happens, you need to navigate back to this screen before relaunching another code.

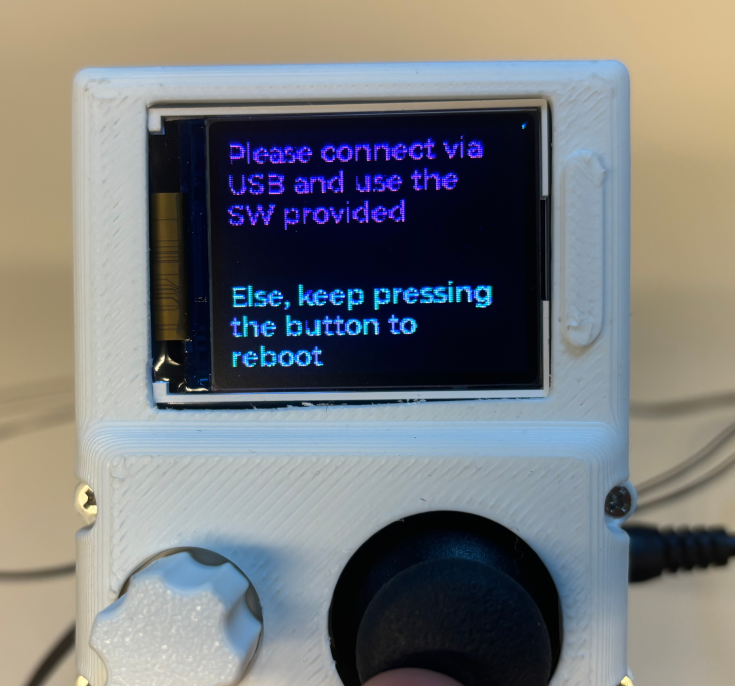
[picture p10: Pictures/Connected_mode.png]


#### 🛠️ Setup

##### 🔗 Plug in the USB-C cable

**Before starting the Docker container**, connect the USB-C cable from the gripper to your computer. The container maps serial devices at startup. If the cable is plugged in afterwards, the device will not be visible inside the container.

Verify that the host detects the device:

```bash
ls /dev/ttyACM* /dev/ttyUSB*
```

Expected output (the exact device name may vary):

```
/dev/ttyACM0
```

If you see `No such file or directory` for both, the cable is not connected or the driver is not loaded. Do not proceed until the device appears.

---

#### 📡 Launching Scripts

> ⚠️ Make sure the gripper LCD is set to **Connected** mode before running any of the commands below. The "Connected" mode screen must be visible before any commands or code can be launched from the computer. The Python code also works on Windows, you just need to change the / in the command for \ (backslash).

#### Python only

##### 🖥️ Simple Connected Mode (terminal, no GUI)

`simple_connected_mode.py` is the minimal starting point for working with the gripper from Python. It streams force data in burst mode and prints a live table to the terminal (no GUI, no ROS 2). It also includes a basic motor-follows-potentiometer example showing how to send commands back to the ESP32.

To run it with Pixi:
```bash
pixi run connected
```

To run it with Docker or with native installation:
```bash
cd /Hands-on-tutorial-on-3D-tactile-sensor-integration-in-robotic-fingers/Codes/python_codes

python3 simple_connected_mode.py

#To launch on Windows, it would be:
#cd \Hands-on-tutorial-on-3D-tactile-sensor-integration-in-robotic-fingers\Codes\python_codes
#python simple_connected_mode.py
```

Optional arguments:

| Flag | Default | Description |
|---|---|---|
| `-p`, `--com-port` | auto-detect | Serial port of the ESP32 |

The terminal output updates at ~50 Hz and shows:

```
Sample #   42 host=000.040
       S0      S1      S2      S3      S4      S5      S6      S7
Fx |  +00.12  -00.03  ...
Fy |  +00.05  +00.01  ...
Fz |  -01.24  -00.87  ...
G  | X=+00012 Y=-00034 Z=+00981 LSB
P  | joy=(  +12,   -5) btn=0  pot= 2048  motor=  2050
```

Press **Ctrl+C** to stop, the serial connection and background threads are closed automatically.

---

##### 📊 Python-Only Live GUI (no ROS 2)

`BurstMode.py` opens a standalone GUI with real-time force bars, joystick, potentiometer, motor and IMU visualisation, and CSV recording. It connects directly to the ESP32 over serial (no ROS 2 code).

To run it with Pixi:
```bash
pixi run burst-gui
```

To run it with Docker or with native installation:
```bash
cd /Hands-on-tutorial-on-3D-tactile-sensor-integration-in-robotic-fingers/Codes/python_codes

python3 BurstMode.py

#To launch on Windows, it would be:
#cd \Hands-on-tutorial-on-3D-tactile-sensor-integration-in-robotic-fingers\Codes\python_codes
#python BurstMode.py
```
You should see something like this appears:

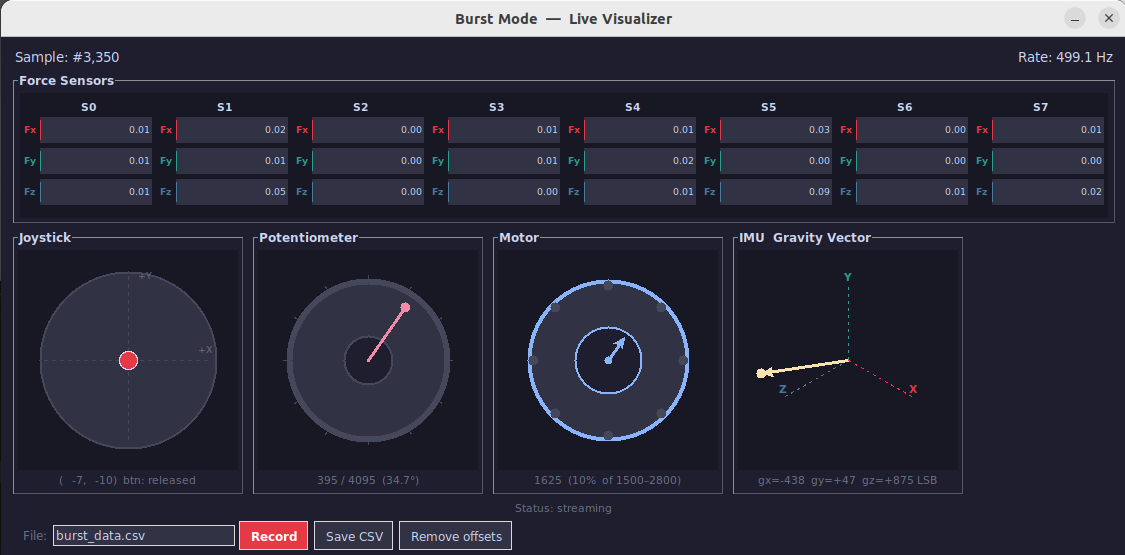
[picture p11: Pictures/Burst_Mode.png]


It is possible to visualise all the data, and control the position of the fingers thanks to the potentiometer, with a position controller. It is also possible to remove the current offset with the button "Remove offset", and save the data.

Optional arguments:

| Flag | Default | Description |
|---|---|---|
| `-p`, `--com-port` | auto-detect | Serial port of the ESP32 |
| `--shear-scale` | `2.0` | Shear force Fx/Fy at full bar deflection, in each direction |
| `--normal-scale` | `5.0` | Normal force Fz at full bar deflection, in each direction |
| `--poll-ms` | `50` | GUI refresh interval in milliseconds |
| `--no-motor-pot` | off | Disable automatic motor follow from potentiometer |

CSV files are saved to `Codes/record_data/`.

---
#### ROS2 codes

##### 🔨 Build the ROS 2 workspace

You need to run this process every time you change the ROS2 code for the changes to take effect.

To run it with Pixi:
```bash
pixi run build
```

To run it with Docker inside the container or with native installation:

```bash
cd /Hands-on-tutorial-on-3D-tactile-sensor-integration-in-robotic-fingers/Codes/ros2_ws

colcon build
source install/setup.bash
```

##### 🖐️ Tactile Finger Visualisation (ROS 2)

Displays a live per-finger tactile map for the two-finger gripper. Run the ESP32 bridge first, then launch this node standalone.

To run it with Pixi:
```bash
#Starts both nodes in one terminal (Ctrl+C stops both)
pixi run tactile-viz
```

To run it with Docker inside the container or with native installation:
```bash
#On one terminal
ros2 run ros2_tactile_robot esp_bridge_node 

#Then on another terminal, go to the docker image with docker exec -it docker3dsensors bash
#Then go to ROS2 folder, build and source
ros2 run ros2_tactile_robot tactile_finger_gui_node
```

You should see something like the window below, showing the forces on each taxel and the total moment Mz for each finger:

<p align="center">
  Visualisation of the sensor
</p>

**Sensor dot encoding** — each dot represents one taxel:

| Visual property | Sensor signal |
|---|---|
| Dot **size** | Normal force Fz — larger = more contact |
| Dot **colour** | Fz magnitude — orange (light force) → red (heavy force) |
| Dot **X displacement** | Lateral shear Fx |
| Dot **Y displacement** | Lateral shear Fy |

The bottom status bar displays the summed Fx, Fy, Fz and Mz for each finger in real time.

**Button:** `Remove offsets` — captures the current readings as a zero baseline (tare). Press it before any measurement to remove drift or gravity offsets.

**Potentiometer:** the gripper can also be opened and closed directly from this view, turning the potentiometer drives the motor, exactly as in the burst-mode GUI. The full potentiometer sweep (0–4095) is mapped onto the safe travel range, so the whole turn is usable and the commanded position never leaves that range.

| Parameter | Default | Description |
|---|---|---|
| `motor_follows_pot` | `true` | Set to `false` to decouple the potentiometer from the motor |

```bash
ros2 run ros2_tactile_robot tactile_finger_gui_node --ros-args -p motor_follows_pot:=false
```

---

##### 🚀 Full System Launch (ROS 2)

Starts all nodes: ESP32 bridge, sensor processing, motor control, joystick, potentiometer, LCD, desktop GUI, and RViz. Like the Burst mode with Python, you will be able to visualise every component's data, save the data in a CSV file and control the gripper with the joystick. You will also have a visualisation in RViz of the force cylinder on each taxel:

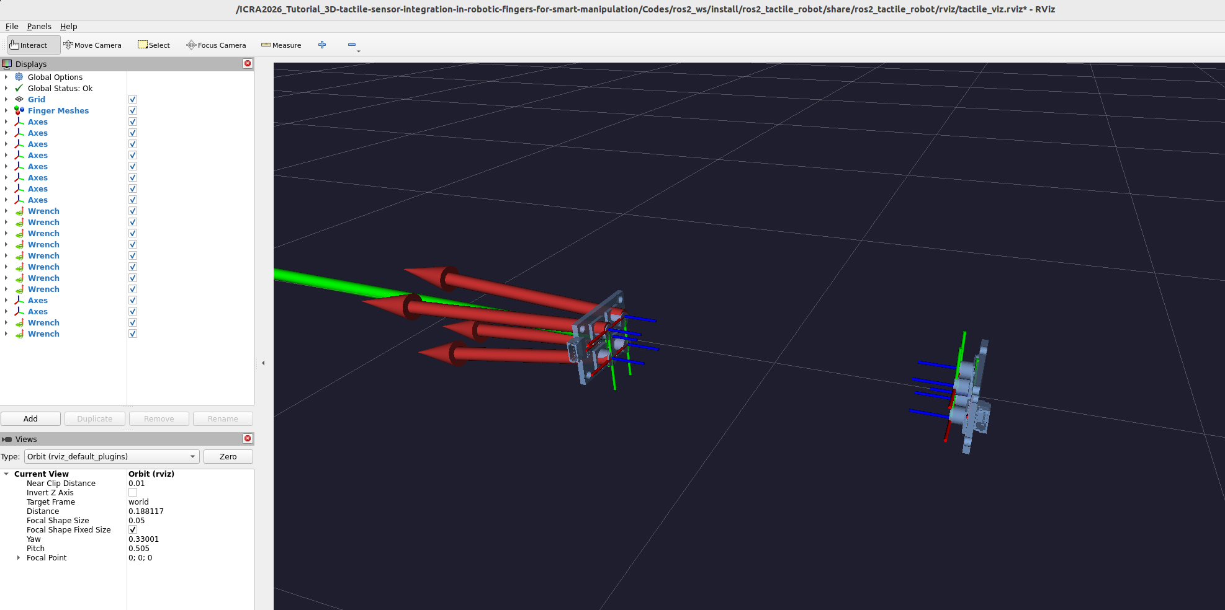
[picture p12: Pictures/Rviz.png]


<p align="center">
  Burst mode with ROS2
</p>

**How it works:** `esp_bridge_node` connects to the ESP32 over serial, streams raw force vectors on `/esp/force`, and publishes the TF frames and mesh markers for RViz. The `gui_node` subscribes to `/esp/force`, applies the tare offset, and publishes tared per-finger and total wrenches (`/tactile/wrench/*`) that drive the force cylinders in RViz. It also renders the live GUI with force bars and CSV recording. The `sensor_node` runs contact detection; `motor_node` arbitrates motor commands from the joystick, potentiometer, and GUI; `joystick_node` and `potentiometer_node` translate peripheral inputs into velocity and motor setpoints; and `lcd_node` updates the on-board display.

To launch the code, don't forget to build and run this:
```bash
#for Pixi, from the repository root
pixi run launch-all

#With Docker / native, once the workspace is built and sourced
ros2 launch ros2_tactile_robot full_system.launch.py
```

Optional arguments (use `pixi shell` first if you are on Pixi, then the plain `ros2 launch` command):

| Argument | Default | Description |
|---|---|---|
| `com_port` | auto-detect | Serial port of the ESP32 |
| `gui` | `true` | Set to `false` to disable the desktop GUI |
| `motor_follows_pot` | `true` | Set to `false` to decouple the potentiometer from the motor |
| `rviz` | `true` | Set to `false` to skip RViz |

Example, with explicit port:

```bash
ros2 launch ros2_tactile_robot full_system.launch.py com_port:=/dev/ttyUSB0 gui:=false rviz:=false
```

---

##### 🎛️ PID Force Control Launch (ROS 2)

Starts the adaptive force controller together with a real-time **Fn / Fg** plot. The potentiometer sets the target normal force (0–5 N).

The controller uses the following structure:
- **Exponential low-pass filter on `fn` and `fg`** (`alpha` parameter): smooths sensor noise before the error is computed. A higher `alpha` gives faster response but more noise; a lower value gives smoother output but slower tracking.
- **Symmetric deadband**: no motor command is sent when `|error| ≤ deadband_n` (the same `deadband_n` magnitude applies on both the over-force and under-force side). This prevents the motor from hunting around the setpoint when the force is already close to the target.
- **Minimum target guard**: the controller is fully inhibited when the target force is below 0.1 N (integral and derivative reset, and the gripper actively opens to release any residual contact force). This prevents the gripper from holding a leftover force when the potentiometer is at zero.
- **Startup auto-zero**: The GUI **Remove offset** button re-publishes on `/pid/tare` at any moment — open the gripper, press the button to re-zero both the PID controller and the GUI plot/offsets.

The gains (Kp, Ki, Kd), the `alpha` and `deadband_n` parameters should be chosen based on the object being grasped. A reference table is provided below: stiffer objects tolerate lower gains, while softer or more delicate objects benefit from higher gains and tighter deadbands to track the target force more precisely.

The GUI displays four live values:
- **Fn**: total normal force on the object applied by the 2 fingers.
- **Fg** : component of the total contact force aligned with gravity thanks to IMU data.
- **Fg/Fn** ratio — grasp-stability indicator:
  - **Too low**: the grip is not tight enough and slippage may occur.
  - **Too high**: excessive force is being applied, which can damage fragile objects.
- **Amp** : peak-to-peak amplitude of the Fg/Fn ratio over a rolling window of x samples. Spikes during slip events / vibrations and is a useful micro-slip indicator.

```bash
#With Pixi, from the repository root
pixi run pid

#With Docker / native, once the workspace is built and sourced
ros2 launch ros2_tactile_robot pid_force_control.launch.py
```

You should see something like this:
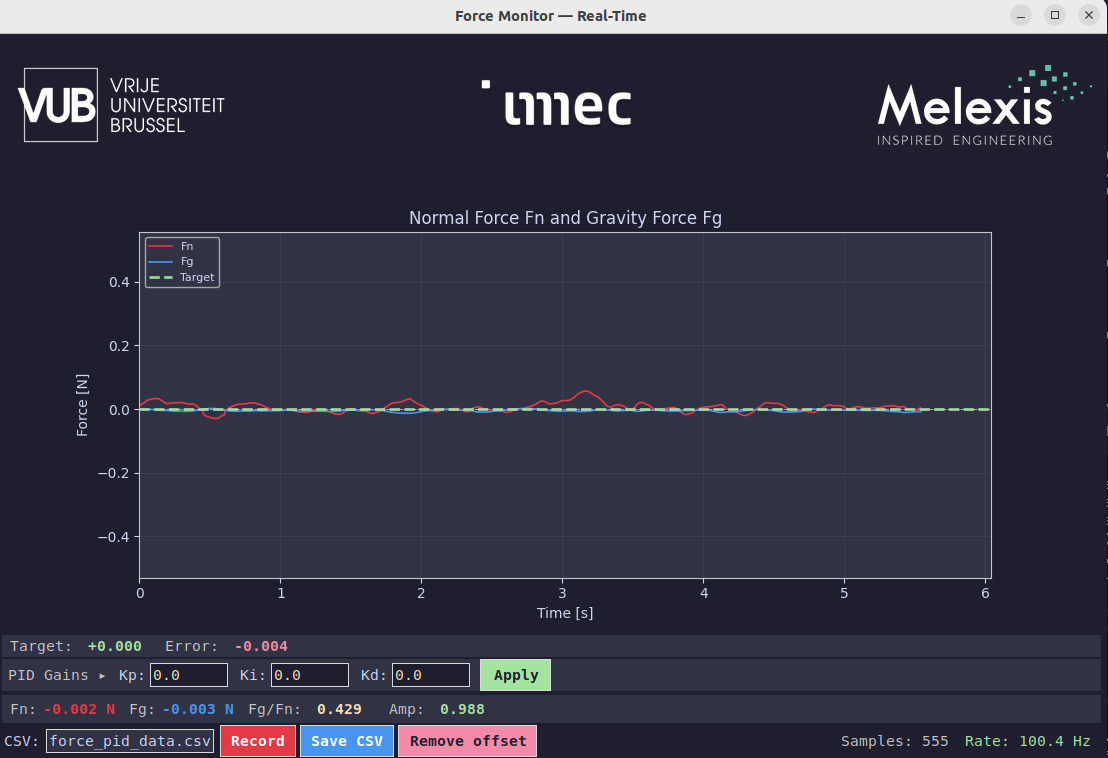
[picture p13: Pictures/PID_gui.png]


<p align="center">
  PID Gui
</p>

Optional arguments (use `pixi shell` first if you are on Pixi, then the plain `ros2 launch` command):

| Argument | Default | Description |
|---|---|---|
| `com_port` | auto-detect | Serial port of the ESP32 |
| `kp` | `0.0` | Proportional gain |
| `ki` | `0.0` | Integral gain |
| `kd` | `0.0` | Derivative gain |
| `alpha` | `0.80` | LPF weight applied to `fn` and `fg` (0 = frozen, 1 = raw) |
| `deadband_n` | `0.20` | Error deadband in N — no motor command within this band |
| `window_s` | `20.0` | Rolling time window of the force plot in seconds |

> ⚠️ `kp`, `ki` and `kd` all default to `0.0`. If you launch `pid_force_control.launch.py` without overriding them, the controller computes zero correction and the motor will not move (the node also logs a warning to this effect on startup). Pick values from the reference table below and pass them explicitly, e.g. `kp:=11 kd:=25`.

**Reference gain values (per object type; they can be found in the BOM for test):**

| Object | Kp | Kd | alpha | deadband |
|---|---|---|---|---|
| CUBE | 11 | 25 | 0.70 | 0.20 N |
| SPONGE | 20 | 28 | 0.75 | 0.15 N |
| CUP | 28 | 35 | 0.80 | 0.10 N |

---

### 3. 👁️ View Forces

Displays live Fx, Fy, Fz readings and contact detection for both fingers on the LCD. Press the joystick to return to the main menu.

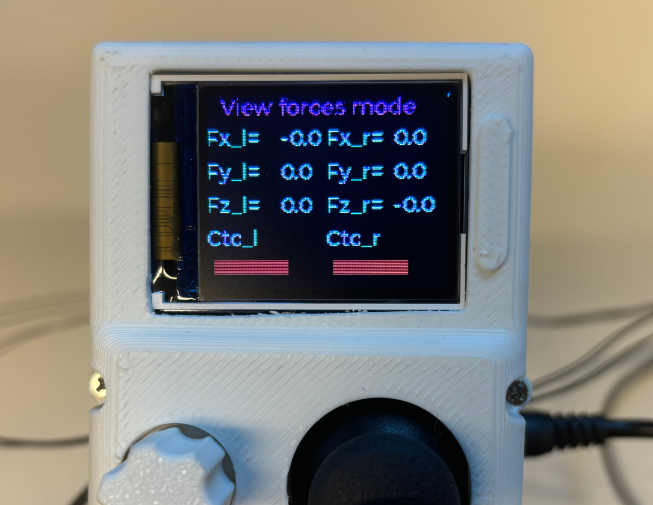
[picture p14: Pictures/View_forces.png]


---

## 💾 CSV Recording Format

All three GUIs (`BurstMode.py`, `gui_node.py`, `pid_gui_node.py`) save recordings to `Codes/record_data/` with the same column layout, so the same post-processing scripts can be used across all tools. Each row is one sample, timestamped from the start of the recording. The columns are, in order:

| # | Column | Description |
|---|---|---|
| 1 | `time_s` | Time since record start in seconds |
| 2–25 | `Sensor{i}_Fnormal [N]`, `Sensor{i}_Fshear_X [N]`, `Sensor{i}_Fshear_Y [N]` (i = 1…8) | Tared per-taxel normal (Fz) and shear (Fx, Fy) forces — 3 columns per sensor × 8 sensors |
| 26–31 | `Left finger - force/torque in x/y/z` | Sum of the 4 left-finger taxel forces and computed torque around each axis |
| 32–37 | `Right finger - force/torque in x/y/z` | Sum of the 4 right-finger taxel forces and computed torque around each axis |
| 38–43 | `Total tactaxis - force/torque in x/y/z` | Combined gripper wrench (firmware sign convention: `fx_tot=fx_L+fx_R`, `fy_tot=fy_L−fy_R`, `fz_tot=fz_L−fz_R`) |
| 44 | `Position gripper` | Motor encoder position (0–4095) |
| 45 | `Gravity force Fg [N]` | Component of the total contact force aligned with gravity |
| 46 | `Normal force Fn [N]` | Total normal grip force `= −(fz_L + fz_R)` |
| 47 | `Ratio Fg/Fn [-]` | Grasp-stability ratio — high `Fg/Fn` ≈ near slip, low ≈ over-gripping |
| 48 | `Target force [N]` | PID target derived from the potentiometer (only meaningful for `pid_gui_node`; empty otherwise) |
| 49 | `Fg/Fn ratio peak-to-peak amplitude  [-]` | Rolling-window peak-to-peak amplitude of the Fg/Fn ratio (window size can be chosen) — micro-slip / vibration indicator |

---

## 📶 ROS 2 Topics (quick reference)

Don't hesitate to do the following command to see the list of topics when launching a code and see what each topic is publishing:

```bash
ros2 topic list

#Then, to see what is published
ros2 topic echo <name of the topic>
```

### Published by `esp_bridge_node`

| Topic | Type | Description |
|---|---|---|
| `/esp/force` | `std_msgs/Float32MultiArray` | 8 sensors × 3 floats (Fx, Fy, Fz); sensors 0–3 = left finger, 4–7 = right finger |
| `/esp/imu` | `sensor_msgs/Imu` | BNO055 gravity vector (linear_acceleration field, in m/s²) |
| `/esp/joystick` | `sensor_msgs/Joy` | Joystick axes [x, y] and button state |
| `/esp/potentiometer` | `std_msgs/Int32` | Raw potentiometer value (0–4095) |
| `/esp/motor_position` | `std_msgs/Int32` | Current motor position |
| `/esp/status` | `std_msgs/String` | JSON acquisition status from the ESP32 |
| `/tactile/markers` | `visualization_msgs/MarkerArray` | STL mesh markers for RViz |

### Subscribed by `esp_bridge_node`

| Topic | Type | Description |
|---|---|---|
| `/motor/drive` | `std_msgs/Float32MultiArray` | Motor command `[position, speed, acceleration]` |

### Published by `gui_node` (tared wrenches, derived from `/esp/force`)

| Topic | Type | Description |
|---|---|---|
| `/tactile/wrench/left_finger` | `geometry_msgs/WrenchStamped` | Summed wrench for the left finger |
| `/tactile/wrench/right_finger` | `geometry_msgs/WrenchStamped` | Summed wrench for the right finger |
| `/tactile/wrench/total` | `geometry_msgs/WrenchStamped` | Total gripper wrench (Tactaxis convention) |
| `/tactile/wrench/left_0..3` | `geometry_msgs/WrenchStamped` | Per-sensor wrench, left finger (one topic per taxel) |
| `/tactile/wrench/right_0..3` | `geometry_msgs/WrenchStamped` | Per-sensor wrench, right finger (one topic per taxel) |

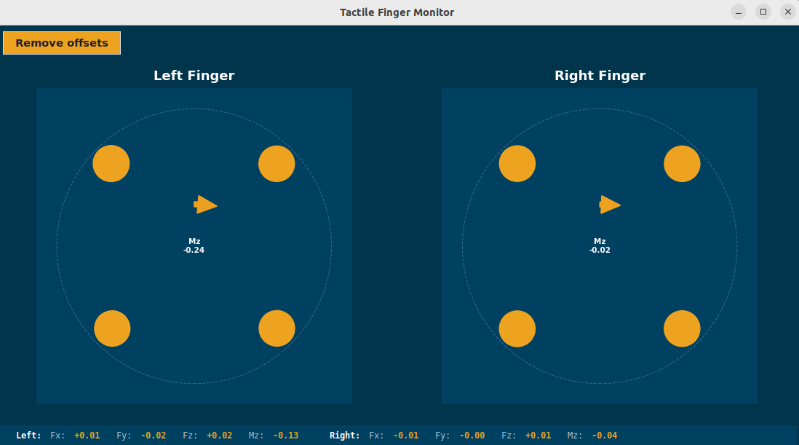
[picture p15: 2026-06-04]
Pictures/Visualisation_sensors.png

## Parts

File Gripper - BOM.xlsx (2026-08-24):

Part number | Name | Quantity needed for 1 kit | Amazon Link | Other Link | Comments | Total cost (€)
3DPrinted1 | Top_Plate | 1 | - | PincOpen Github (https://github.com/pollen-robotics/PincOpen/tree/main/cad) | 3D printed part for the PincOpen gripper from PollenRobotics | 0.74
3DPrinted2 | Cam | 1 | - | PincOpen Github (https://github.com/pollen-robotics/PincOpen/tree/main/cad) | 3D printed part for the PincOpen gripper from PollenRobotics | 0.10
3DPrinted3 | Bottom_Plate | 1 | - | PincOpen Github (https://github.com/pollen-robotics/PincOpen/tree/main/cad) | 3D printed part for the PincOpen gripper from PollenRobotics | 0.66
3DPrinted4 | Internal_Rod | 2 | - | PincOpen Github (https://github.com/pollen-robotics/PincOpen/tree/main/cad) | 3D printed part for the PincOpen gripper from PollenRobotics | 0.24
3DPrinted5 | External_Rod | 2 | - | PincOpen Github (https://github.com/pollen-robotics/PincOpen/tree/main/cad) | 3D printed part for the PincOpen gripper from PollenRobotics | 0.08
3DPrinted6 | Distal_Rod | 2 | - | PincOpen Github (https://github.com/pollen-robotics/PincOpen/tree/main/cad) | 3D printed part for the PincOpen gripper from PollenRobotics | 0.07
3DPrinted7 | Driving_Rod | 2 | - | PincOpen Github (https://github.com/pollen-robotics/PincOpen/tree/main/cad) | 3D printed part for the PincOpen gripper from PollenRobotics | 0.06
3DPrinted8 | Removable_Tip | 2 | - | See Github repository | 3D printed part for the PincOpen gripper from PollenRobotics (adapted to fit Tactaxis sensors in it) | 0.07
3DPrinted9 | Distal_Shell | 2 | - | See Github repository | 3D printed part for the PincOpen gripper from PollenRobotics (adapted to fit Tactaxis sensors in it) | 0.10
3DPrinted10 | Motor_Flange | 1 | - | PincOpen Github (https://github.com/pollen-robotics/PincOpen/tree/main/cad) | 3D printed part for the PincOpen gripper from PollenRobotics | 0.03
3DPrinted11 | Support_gripper | 1 | - | See Github repository | Support to place the main board, the external PCB and tha attach it on the gripper | 3.92
3DPrinted12 | Cover_main_board | 1 | - | See Github repository | Cover to protect and hid the main board on the support of the gripper | 0.35
3DPrinted13 | Cover_external_PCB | 1 | - | See Github repository | Cover to protect and hid the external PCB on the support of the gripper | 0.48
3DPrinted14 | Potentiometer_Knob | 1 | - | See Github repository | Knob to cover the potentiometer | 0.07
Electronics1 | Feetech STS3215 | 1 | Electronics1 (https://www.amazon.fr/Suoumwa-Servos-STS3215-Robotique-SO-ARM100/dp/B0F131YB1Z) | Gotronic (https://www.gotronic.fr/art-servo-serie-360-deg-12v-48041.htm) | Servo motor to control the gripper | 23.90
Electronics2 | Cable USB A - USB C (1m) | 1 | - | Digikey (https://www.digikey.ch/en/products/detail/cvilux-usa/DH-20M50052/13177409) | To connect the main board to the PC and control the gripper with python codes | 1.57
Electronics3 | Tactaxis sensors from Melexis - 4 taxels | 2 | - | From Melexis | 3D forces sensing from Melexis | 55.75
Electronics4 | Cover sensors | 2 | - | - | Covers on the top of the sensors to have a better grasp | 3.00
Electronics5 | Cables for Tactaxis sensors (25cm) | 2 | - | Digikey (https://www.digikey.ch/en/products/detail/jst-sales-america-inc/A04SR04SR30K254A/9922185) | Cables to connect the sensors to the board | 2.76
Electronics6 | Cables between PCB cable | 1 | - | Digikey (https://www.digikey.com/en/products/detail/molex/0151341401/7929160) | Cable to connect PCB to the main board | 6.26
Electronics7 | Cable Power supply | 1 | - | Ampul (https://ampul.eu/fr/alimentations-enfichables/3231-alimentation-electrique-12v-5a-55x25mm) | Power supply for the servo controller | 15.72
Electronics8 | Main board | 1 | - | - | Designed by Melexis, allow to control the full gripper | 40.00
Electronics9 | External PCB | 1 | - | - | Designed by Melexis, allow to connect the full system with the potentiometer, the joystick and the LCD screen | 10.00
Electronics10 | LCD screen ST7735 | 1 | Electronics10 (https://www.amazon.com.be/-/en/DollaTek-128x128-Display-screen-Arduino/dp/B07QJ27XFC) | Ebay (https://www.ebay.de/itm/306660440487?emsid=e11400.m144671.l197929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) | Show the GUI to the user on the external PCB | 5.38
Electronics11 | Joystick | 1 | - | Digikey (https://www.digikey.ch/en/products/detail/sparkfun-electronics/09032/6823623) | To select option on the screen, used also as a button | 4.59
Electronics12 | Potentiometer | 1 | - | Digikey (https://www.digikey.com/en/products/detail/tt-electronics-bi/P120PK-Y25BR10K/5957454) | To increase the force wanted by the user | 1.22
Electronics13 | Header LCD | 1 | - | Digikey (https://www.digikey.com/en/products/detail/sullins-connector-solutions/PPTC081LFBN-RC/810147) | Header to connect the LCD screen to the external PCB | 0.50
Mechanics1 | Parallel Pin 3 x 16 h6 | 4 | Mechanics1 (https://www.amazon.com.be/Roulement-aiguille-acier-localisation-cylindrique/dp/B0DBHTC7MG?th=1) | Vital-part (https://www.vital-parts.co.uk/rounded-parallel-pins-din-7/4762-dow7-3-16-a1) | Used to mount the PincOpen gripper from PollenRobotics | 1.47
Mechanics2 | Parallel Pin 3 x 24 h6 | 4 | Mechanics2 (https://www.amazon.com.be/-/en/ByNGSDCC/dp/B0G25J2RR8?s=industrial) | VitalPart (https://www.vital-parts.co.uk/rounded-parallel-pins-din-7/4769-dow7-3-24-a4) | Used to mount the PincOpen gripper from PollenRobotics | 1.31
Mechanics3 | Plain Bearing 3 x 6 x 5 mm | 4 | Mechanics3 (https://www.amazon.com.be/M%C3%A9tallurgie-poudres-Doublure-Diam%C3%A8tre-int%C3%A9rieur/dp/B0DFW71NB1) | Aliexpress (https://nl.aliexpress.com/item/1005005270665270.html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:) | Used to mount the PincOpen gripper from PollenRobotics | 1.06
Mechanics4 | Screw thermoplastic 2.5 x 8 mm | 24 | Mechanics4 (https://www.amazon.com.be/Xuro-autotaraudeuses-frais%C3%A9e-cruciforme-carbone/dp/B0FPBLRTVZ?th=1) | Aliexpress (https://fr.aliexpress.com/item/1005006883251273.html) | Used to mount the PincOpen gripper: body of the gripper (11) + used to mount the support with the gripper (5)+to attach the support (4) + top of PCB (4) | 2.46
Mechanics5 | Screw M3 x 0.50 x 10 mm | 4 | Mechanics5 (https://www.amazon.com.be/Lot-t%C3%AAte-cylindrique-pans-creux/dp/B0DQV56D6V?th=1) | RS (https://befr.rs-online.com/web/p/socket-screws/8740999) | Used to mount the PincOpen gripper | 0.49
Mechanics6 | Screw M2 x 8 mm | 16 | Mechanics6 (https://www.amazon.com.be/dp/B0FVM6ZV7Y?ref=ppx_yo2ov_dt_b_fed_asin_title&th=1) | RS (https://fr.rs-online.com/web/p/vis-a-metaux/0190434) | Used to mount the top plate of the support (4) + board (4) + PCB(4) + for touch sensors (2x4) | 1.52
Mechanics7 | Hex Nut M2 | 4 | - | RS (https://befr.rs-online.com/web/p/hex-nuts/0560271) | Used to attach the screws of the touch sensors | 0.12
Mechanics8 | Brass insert M3 | 4 | Mechanics8 (https://www.amazon.com.be/dinsertion-filetage-imprimante-thermique-thermofusible/dp/B0DM2QWXVG?th=1) | - | Used to mount the PincOpen gripper | 1.77
Mechanics9 | Brass insert M2 | 8 | Mechanics9 (https://www.amazon.com.be/dinsertion-filetage-imprimante-thermique-thermofusible/dp/B0DM2LXDTD?th=1) | - | Used to mount the main board and the external PCB on the support_gripper | 3.57
Tool1 | 2,5 mm hex key | 1 | Tool1 (https://www.amazon.com.be/-/en/QUARKZMAN-Wrench-L-Shaped-Wrenches-Vanadium/dp/B0D4QRXJ42?s=home-improvement) | - | Tools: Allenkey for M3 | 1.00
Tool2 | Small Phillips screwdriver | 1 | Tool2 (https://www.amazon.com.be/-/en/Dual-component-Phillips-screwdriver-No-100/dp/B0B2SBSQL6?s=electronics) | - | Tools: Screwdriver for M2 | 17.12
Object1 | Wood cubes | 1 | Object1 (https://www.amazon.com.be/-/en/Kurtzy-Wooden-Cube-Pieces-Construction/dp/B01BSQ75HA?s=home) | - | Object to grasp: wood cube | 0.42
Object2 | White plastics cups | 1 | Object2 (https://www.amazon.com.be/-/en/Disposable-Plastic-Parties-Birthdays-Hygiene/dp/B08SWMKJ9Z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) | - | Object to grasp: plastic cup | 0.03
Object3 | Sponges | 1 | Object3 (https://www.amazon.com.be/-/en/SPONTEX-vegetable-Packaging-recycled-plastqiue/dp/B0CV46TVY5) | - | Object to grasp: sponge | 2.81
 |  |  |  |  | Total price | 212.77

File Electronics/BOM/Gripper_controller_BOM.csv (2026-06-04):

Name | Description | Designator | Quantity
EVP-AWED4A | Switch | BOOT, RST | 2
GCM155R71C104KA55D | CAP CER 0.1UF 16V X7R 0402 | C1, C4, C5, C6, C8, C10, C11, C15 | 8
GCM1555C1H180JA16D | CAP CER 18PF 50V NP0 0402 | C2, C3 | 2
EEEFK1C101P | Aluminum Electrolytic Capacitors; 100 uF; 16 V; 5.3x5.8mm; 20 %; -55 °C to 105 °C | C7, C16, C17 | 3
GRJ155R60J106ME11D | CAP CER 10UF 6.3V X5R 0402 | C9, C14, C22, C23 | 4
GCM188R71C105KA64D | CAP CER 1UF 16V X7R 0603 | C12, C20, C21 | 3
GRM155R60J684KE19D | CAP CER 0.68UF 6.3V X5R 0402 | C13 | 1
GRM188R61A124KA01D | CAP CER 0.12UF 10V X5R 0603 | C18, C19 | 2
USB4110-GF-A | Connector, USB TYPE-C, Receptacle, Surface Mount, Right Angle, GCT USB4110-GF-A | CON_USB1 | 1
PRTR5V0U2X,215 | TVS DIODE 5.5V SOT143B | D1 | 1
B5819WS-TP | DIODE SCHOTTKY 40V 1A SOD323 | D2, D4, D5 | 3
APHHS1005CGCK | LED GREEN CLEAR CHIP SMD | D3 | 1
742792651 | FERRITE BEAD 600 OHM 0603 1LN | FB2, FB3 | 2
ESP32-S3FH4R2 | IC RF TXRX+MCU BLE 56QFN | IC2 | 1
NCP164ASN330T1G | IC REG LINEAR 3.3V 300MA 5-TSOP | IC3 | 1
53261-1471 | CONN HEADER SMD R/A 14POS 1.25MM | J1 | 1
PJ-102B | Through Hole Right Angle DC Power Jack, 2.5 A, 2.5 mm Center Pin, 3 Position, -25 to 85 degC, RoHS, Bulk | J2 | 1
22-05-7035 | CONN HEADER R/A 3POS 2.5MM MOLEX | MOTOR CON | 1
R-78K5.0-0.5 | 0.5A DC/DC-CONVERTER 'INNOLINE' | PS1 | 1
MMSS8550-H-TP | TRANS PNP 25V 1.5A SOT23 | Q1 | 1
ERJ-2GEJ102X | RES SMD 1K OHM 5% 1/10W 0402 | R1, R2, R6 | 3
ERJ-2RKF22R0X | RES SMD 22 OHM 1% 1/10W 0402 | R3, R4 | 2
ERJ-2RKF3300X | RES SMD 330 OHM 1% 1/10W 0402 | R5, R9, R10, R11 | 4
ERJ-2GEJ103X | RES SMD 10K OHM 5% 1/10W 0402 | R7, R8, R12, R13, R14, R15, R16, R17 | 8
SM04B-SRSS-TB_LF__SN_ | CONN HEADER SMD R/A 4POS 1MM | SArray1, SArray2 | 2
SN74LVC1G126DBVT | IC BUF NON-INVERT 5.5V SOT23-5 | U1 | 1
SN74LVC1G125DBVT | IC BUF NON-INVERT 5.5V SOT23-5 | U2 | 1
BNO055 | IMU ACCEL/GYRO/MAG I2C 28LGA | U3 | 1
ABM8G-40.000MHZ-18-D2Y-T | Crystal 40MHz ±20ppm (Tol) ±30ppm (Stability) 18pF FUND 50? 4-Pin SMD T/R | Y1 | 1

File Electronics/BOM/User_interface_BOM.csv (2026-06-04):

Name | Description | Designator | Quantity
53261-1471 | MOLEX CONN HEADER SMD R/A 14POS 1.25MM | J1 | 1
LCD ST7735 | LCD 1.8" ST7735 | LCD | 1
PRT-14460 | Switch | LEFT, RIGHT | 2
COM-09032 | Thumb Joystick | U4 | 1
P120PK-Y25BR10K | Variable Resistor | VR1, VR2 | 2

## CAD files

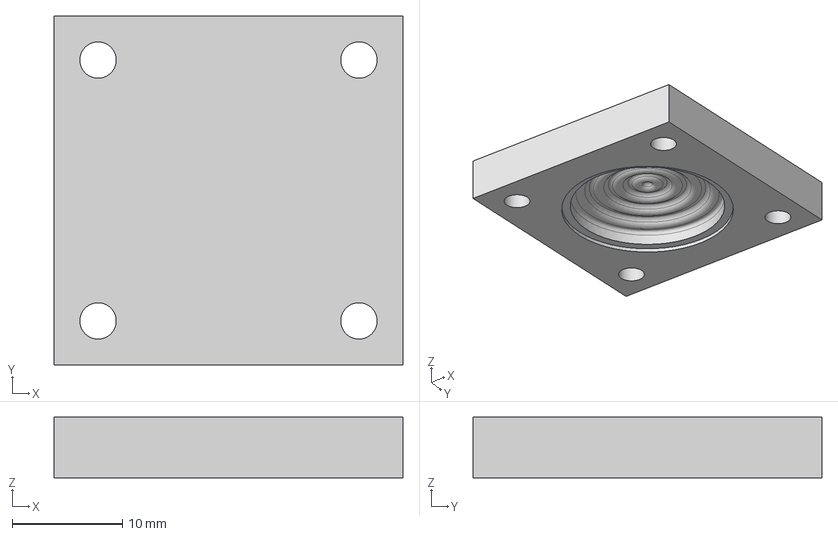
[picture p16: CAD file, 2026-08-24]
Design/step/Tactaxis_PDMS_Cover_Mold_Bottom.STEP
31.7 x 31.7 x 5.50 mm

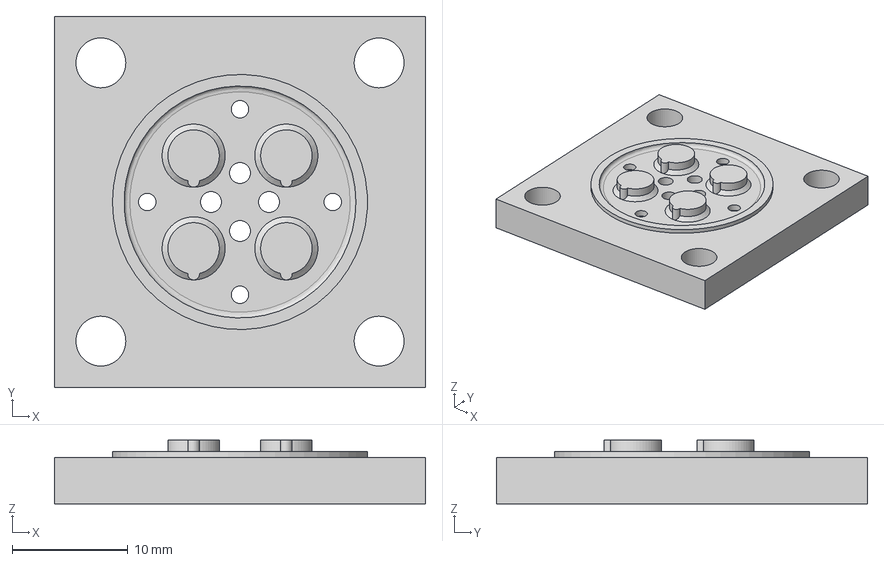
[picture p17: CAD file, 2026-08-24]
Design/step/Tactaxis_PDMS_Cover_Mold_Top.STEP
32.0 x 32.0 x 5.50 mm

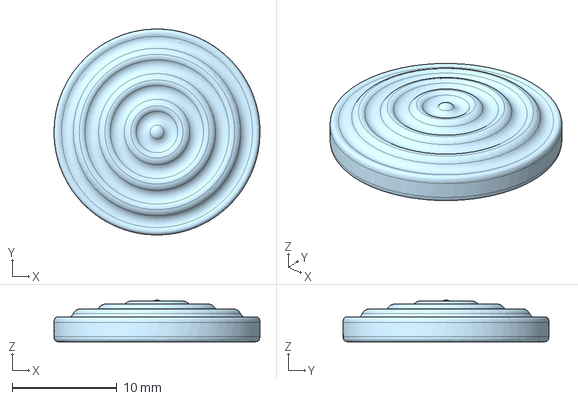
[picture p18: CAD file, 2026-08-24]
Design/step/Tactaxis_PDMS_Cover.STEP
19.7 x 19.7 x 4.00 mm

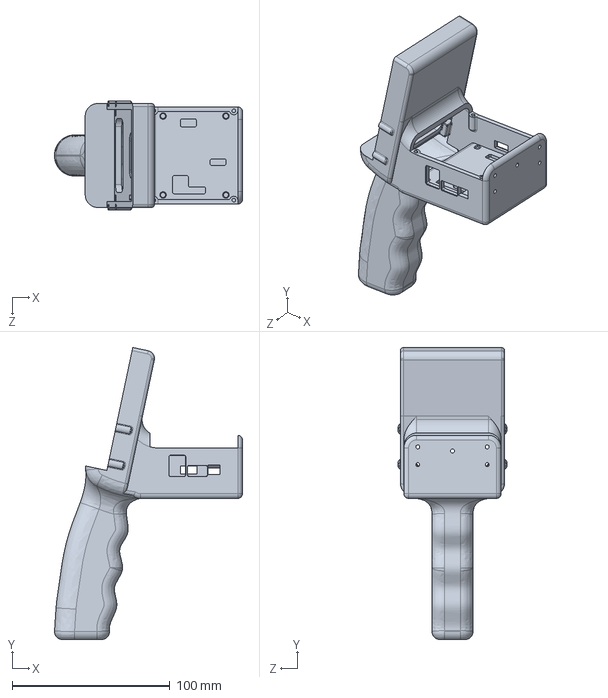
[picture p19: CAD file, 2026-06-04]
Design/step/Head_Housing.STEP
119.1 x 185.0 x 69.0 mm

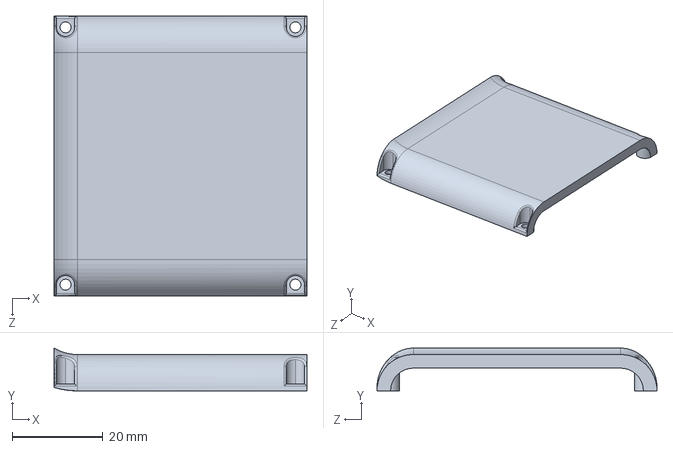
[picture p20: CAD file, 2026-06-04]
Design/step/Top_Panel.STEP
55.6 x 9.42 x 61.6 mm

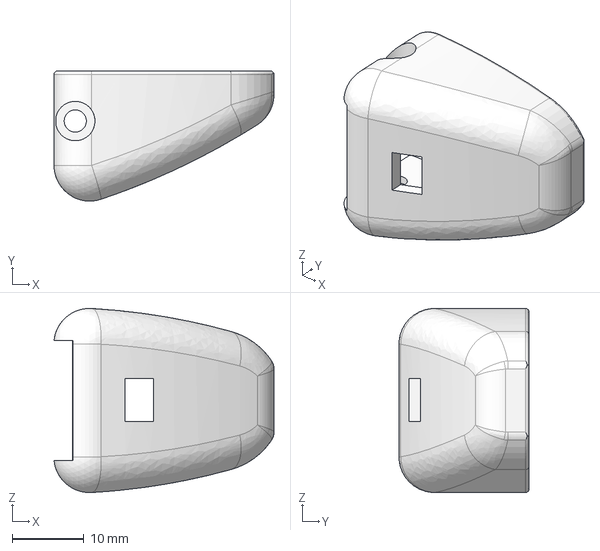
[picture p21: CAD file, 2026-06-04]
Design/step/Distal_Shell.STEP
30.7 x 18.2 x 25.7 mm

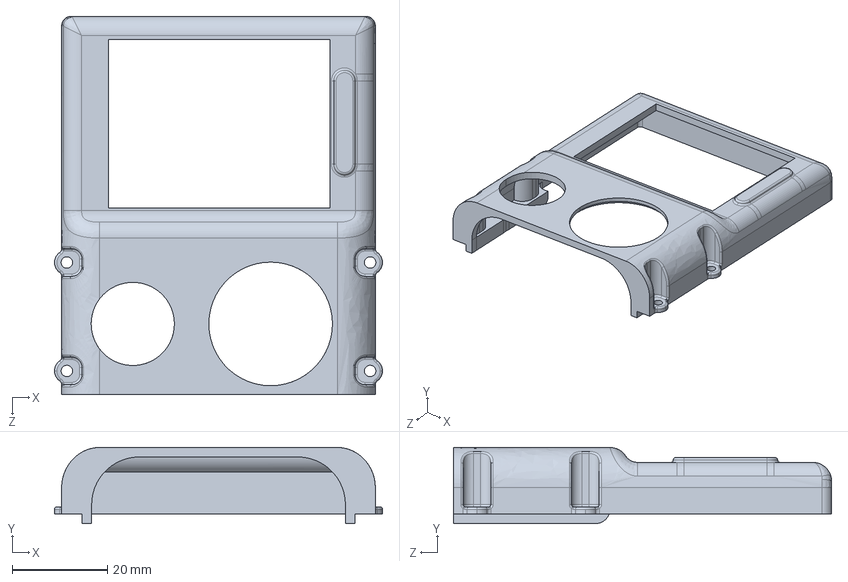
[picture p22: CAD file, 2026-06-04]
Design/step/Interface_Panel.STEP
69.0 x 16.0 x 79.6 mm

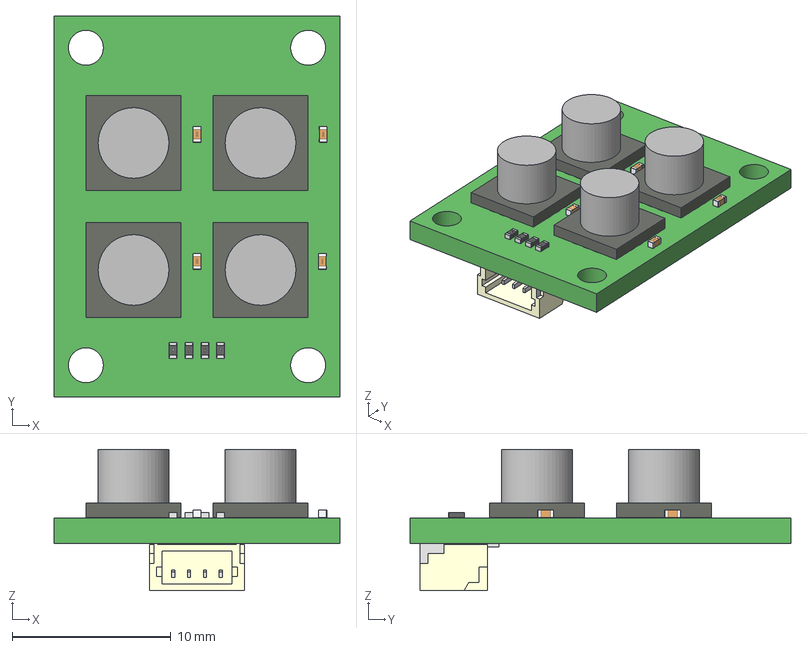
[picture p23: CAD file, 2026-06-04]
Design/step/Tactaxis_Sensor.STEP
18.0 x 24.0 x 8.89 mm
R0402_0402 x 4
SM04B-SRSS_DTL
Extruded x 56
C0402 x 4

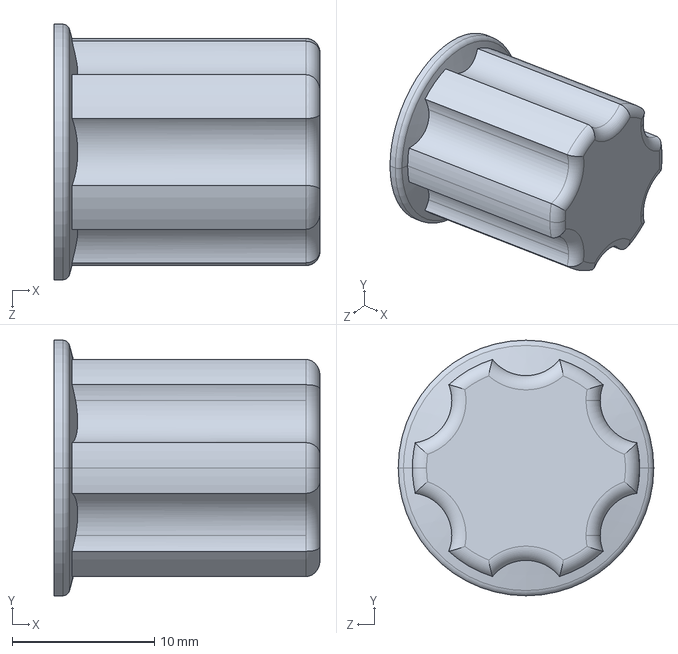
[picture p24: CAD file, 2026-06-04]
Design/step/Potentiometer_Knob.STEP
18.7 x 18.0 x 18.0 mm

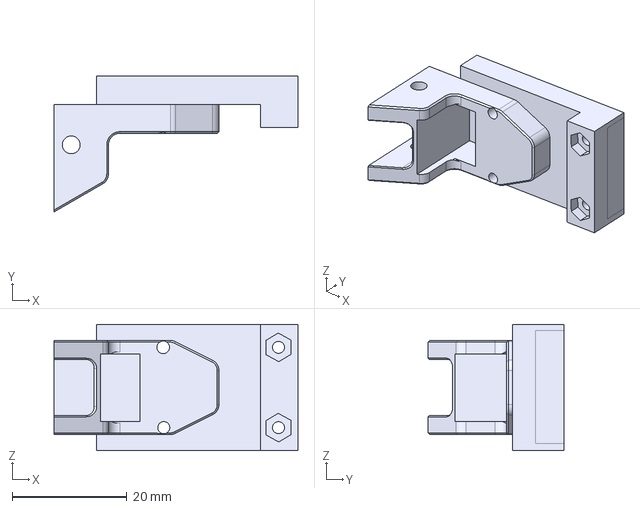
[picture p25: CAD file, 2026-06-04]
Design/step/Removable_Tip.STEP
42.5 x 23.7 x 22.0 mm

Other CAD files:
Design/stl/Distal_Shell.STL
Design/stl/Head_Housing.STL
Design/stl/Interface_Panel.STL
Design/stl/Potentiometer_Knob.STL
Design/stl/Removable_Tip.STL
Design/stl/Tactaxis_PDMS_Cover.STL
Design/stl/Tactaxis_PDMS_Cover_Mold_Bottom.STL
Design/stl/Tactaxis_PDMS_Cover_Mold_Top.STL
Design/stl/Tactaxis_Sensor.STL
Design/stl/Top_Panel.STL

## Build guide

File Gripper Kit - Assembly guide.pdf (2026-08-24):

Brubotics (VUB & imec) : Milan.Francois.T.Amighi@vub.be
Melexis : tls@melexis.com

# Hands-on Tutorial: 3D Tactile Sensor Integration in Robotic Fingers for Smart Manipulation

## 1. 3D Printed Parts list

Part | Quantity | Image
Internal Rod | 2
External Rod | 2
Distal Rod | 2
Removable Tip* | 2
Distal Shell* | 2

Top Plate | 1
Motor Flange | 1
Cam | 1
Driving Rod | 2
Bottom Plate | 1
Head Housing* | 1

Interface panel for Head Housing* | 1
Top panel for Head Housing* | 1
Potentiometer Knob* | 1

*These parts have been added and are not from Pollen Robotics.

## 2. Components list

Component | Quantity | Image
Feetech STS3215 Servo Motor, JST Wire and screws | 1

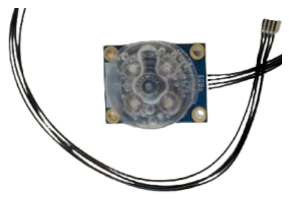
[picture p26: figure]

Touch Sensor, cables and cover of the sensor | 2

Interface PCB and his cable | 1
LCD Screen | 1
Joystick | 1
Potentiometer | 1
Controller PCB | 1
Screw M2 x 8 | 16
Hex Nut M2 | 4
Spacer | 1

Thermoplastic Screw 2.5 × 8 | 24
Screw M3 × 0.50 × 10 | 4
Parallel Pin 3 × 16 h6 | 4
Parallel Pin 3 × 24 h6 | 4
Insert M2 | 8
Insert M3 | 4
Plain Bearing 3 x 6 x 5 | 4
Tools : - Screwdriver KL-1 - Hex Wrench 2.5mm | 2

Test objects | 3
Power supply 12V, 5A | 1
USB-C cable | 1

## 3. Pre-Assembly

Insert the bearings in the provided bores

The bearing is supposed to fit by forcing with hand, or pressed onto a solid surface. No tool is needed here.

If it’s too hard, file or drill the hole a bit and repeat so that it fits tighten.

If the hole is too wide, put a drop of glue

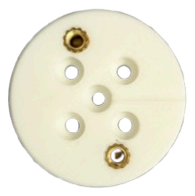
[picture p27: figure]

M3 Brass inserts

Insert M3 brass inserts using a soldering iron.

Make sure that you are on the right side.

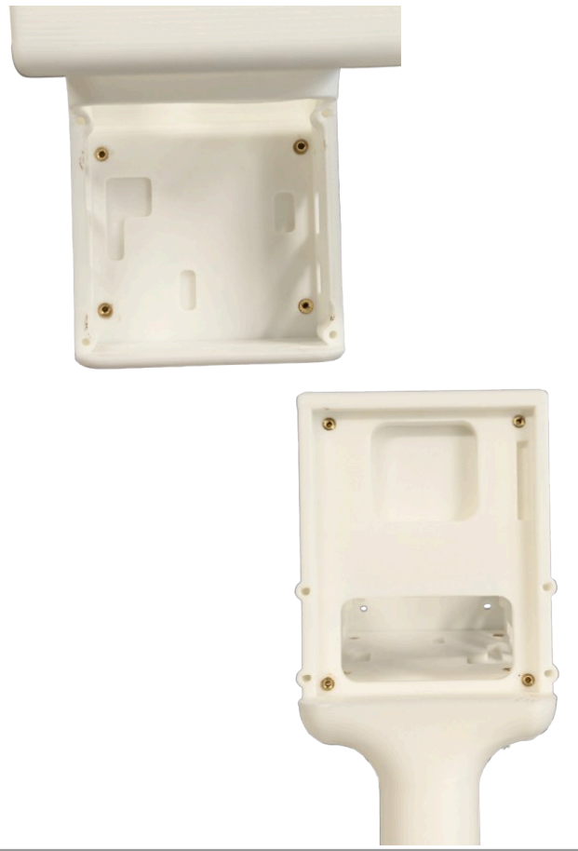
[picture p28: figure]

M2 Brass inserts

Insert M2 brass inserts using a soldering iron.

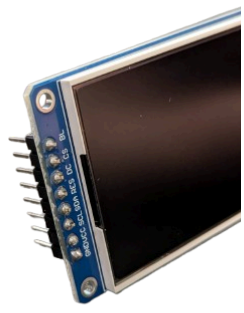
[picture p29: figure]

Screen Soldering

Position the black connective as shown in the picture.

Solder each pin to the card, on the screen side.

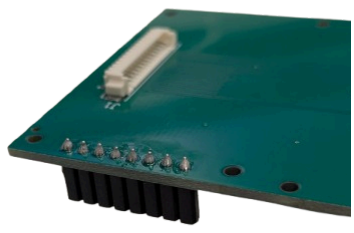
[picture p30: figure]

Interface PCB Soldering

Position the female black connective on the Interface PCB, as shown in the first picture.

Solder each pin on the back of the PCB.

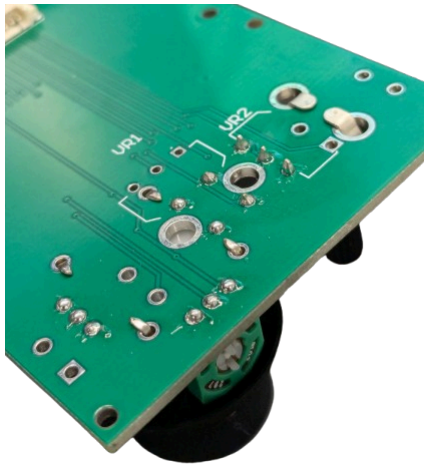
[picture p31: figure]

Position the Joystick on the PCB.
Bend the four metallic stabilizers and solder the pins to the PCB.

Position the Potentiometer to the PCB. Bend the two metallic stabilizers and solder the pins to the PCB.

## 4. Assembly Guide

Follow the steps below to correctly assemble the Parallel-Finger Gripper.

Step 1: Finger Assembly

Note: Repeat this entire process for the other phalanx to build both fingers.

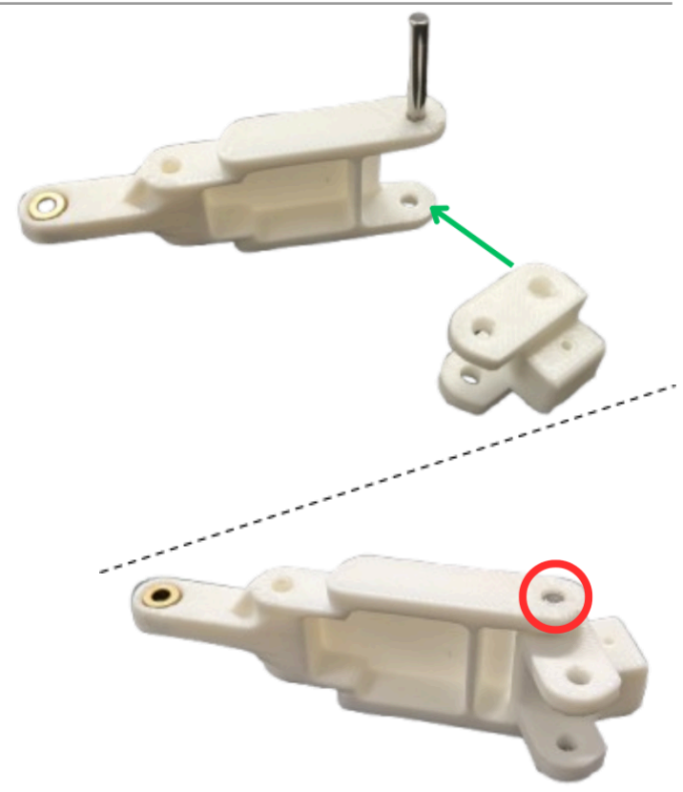
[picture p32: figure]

First Phalanx Construction
Take the Internal Rod (bag A) and position
the Distal Rod (bag A) as shown in the picture (green arrow).

Insert a Parallel Pin 24mm (bag L) into the hole (red circle).

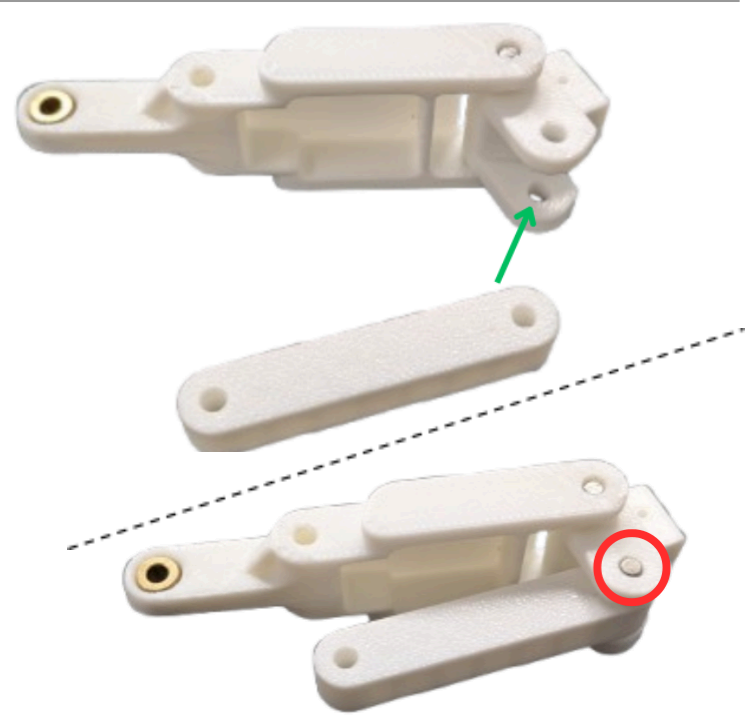
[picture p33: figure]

Position the External Rod (bag A) as shown in the picture (green arrow).

Ensure the External Rod is placed on the hollow side of the phalanx.

Insert the Parallel Pins 16 mm (bag L) into the hole (red circle).

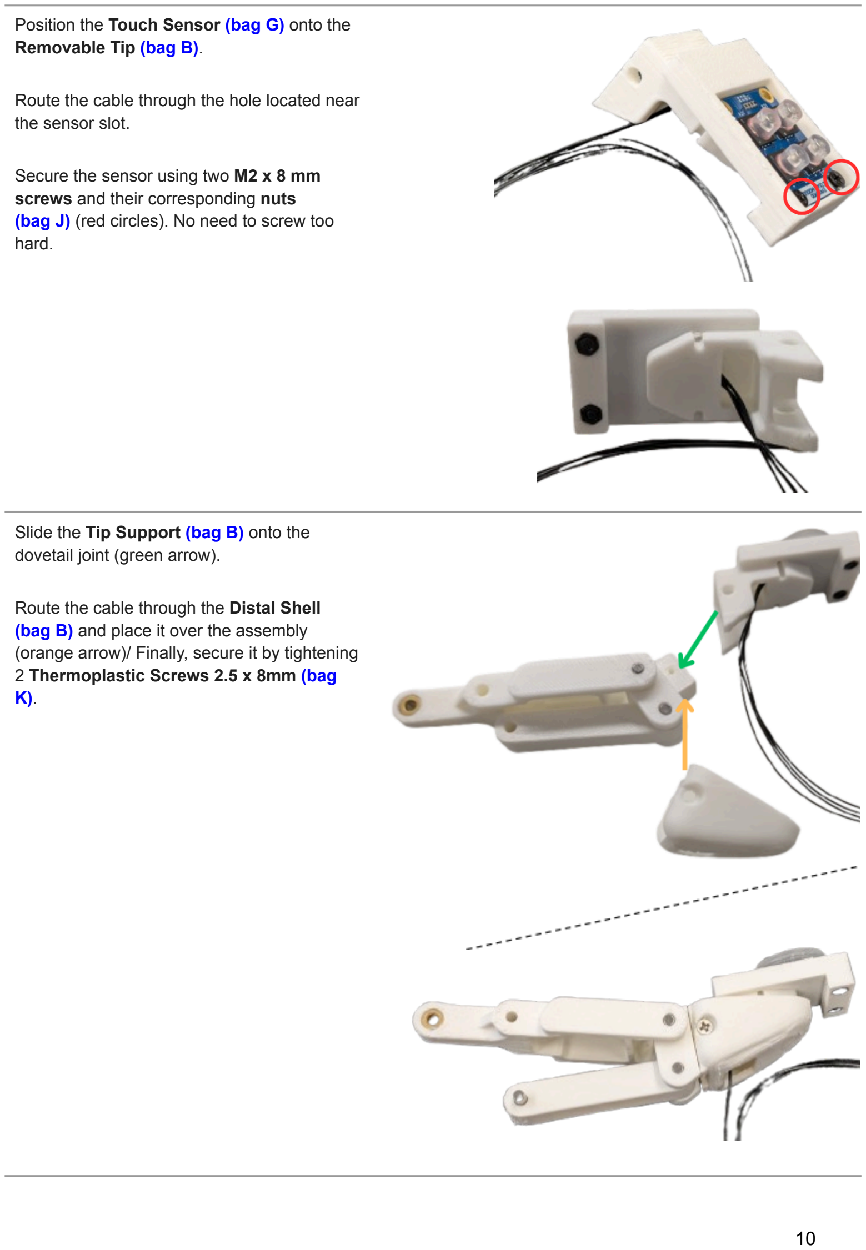
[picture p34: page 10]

Position the Touch Sensor (bag G) onto the Removable Tip (bag B).

Route the cable through the hole located near the sensor slot.

Secure the sensor using two M2 x 8 mm screws and their corresponding nuts (bag J) (red circles). No need to screw too hard.

Slide the Tip Support (bag B) onto the dovetail joint (green arrow).

Route the cable through the Distal Shell (bag B) and place it over the assembly (orange arrow)/ Finally, secure it by tightening 2 Thermoplastic Screws 2.5 x 8mm (bag K).

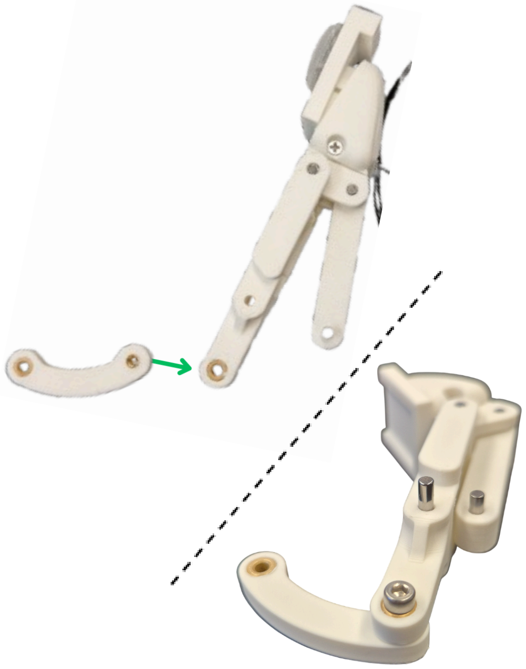
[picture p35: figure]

Attaching the Driving Rods
Right Finger: Place the Driving Rod (bag D) as shown in the picture (green arrow).

Secure it using a Screw M3 x 10mm (bag K) with the allen key.

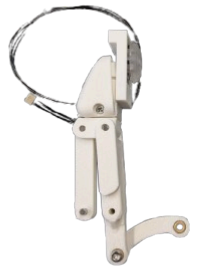
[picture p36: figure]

Attaching the Driving Rods
Left Finger: Place the Driving Rod (bag D) as shown in the picture.
Be careful here, the orientation of the Driving Rod is different from the Right Finger.

Secure it using a Screw M3 x 10mm
(bag K) with the allen key.

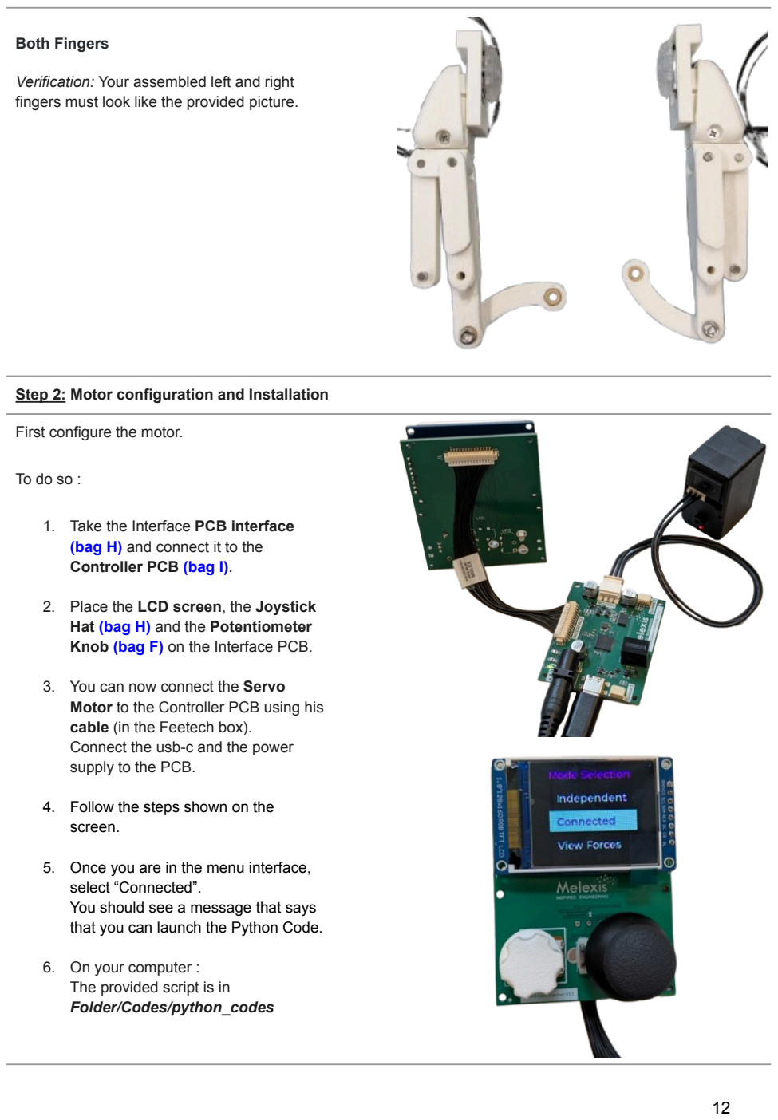
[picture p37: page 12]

Both Fingers

Verification: Your assembled left and right fingers must look like the provided picture.

Step 2: Motor configuration and Installation

First configure the motor.

To do so :

1. Take the Interface PCB interface (bag H) and connect it to the Controller PCB (bag I).
2. Place the LCD screen, the Joystick Hat (bag H) and the Potentiometer Knob (bag F) on the Interface PCB.
3. You can now connect the Servo Motor to the Controller PCB using his cable (in the Feetech box).
Connect the usb-c and the power supply to the PCB.
4. Follow the steps shown on the screen.
5. Once you are in the menu interface, select “Connected”.
You should see a message that says that you can launch the Python Code.
6. On your computer :
The provided script is in
Folder/Codes/python_codes

Use the following command to run it : python3 Motor_initialisation.py You should see the motor turn and go back to its initial state. The motor is now initialized in an “open finger” position. Disconnect all the cables by pulling on the connecters (not the cables), and put away the different parts in their respective bags. We’ll use them again later.

Motor Flange Secure the Motor Flange (bag C) to the Servo Motor using the self-tapping screws provided by Feetech (in the Feetech Servo Motor box).

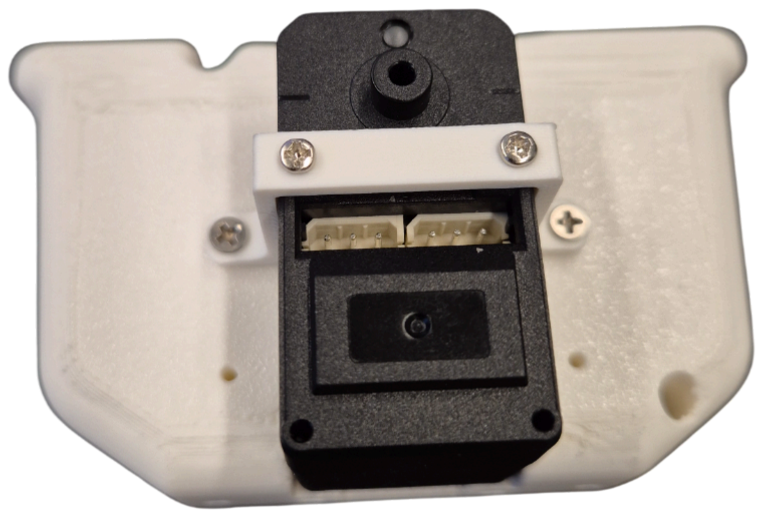
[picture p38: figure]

Motor on Palm: Insert the motor into its designated slot on the palm of the Top Plate (bag C).

Secure it from the top using 2 Thermoplastic Screws 2.5 x 8mm (bag K).

Flip the palm over and insert 2 additional Feetech self-tapping screws from the bottom, as indicated in the picture (red circles).

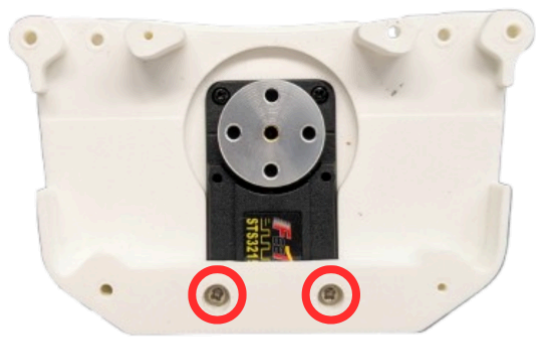
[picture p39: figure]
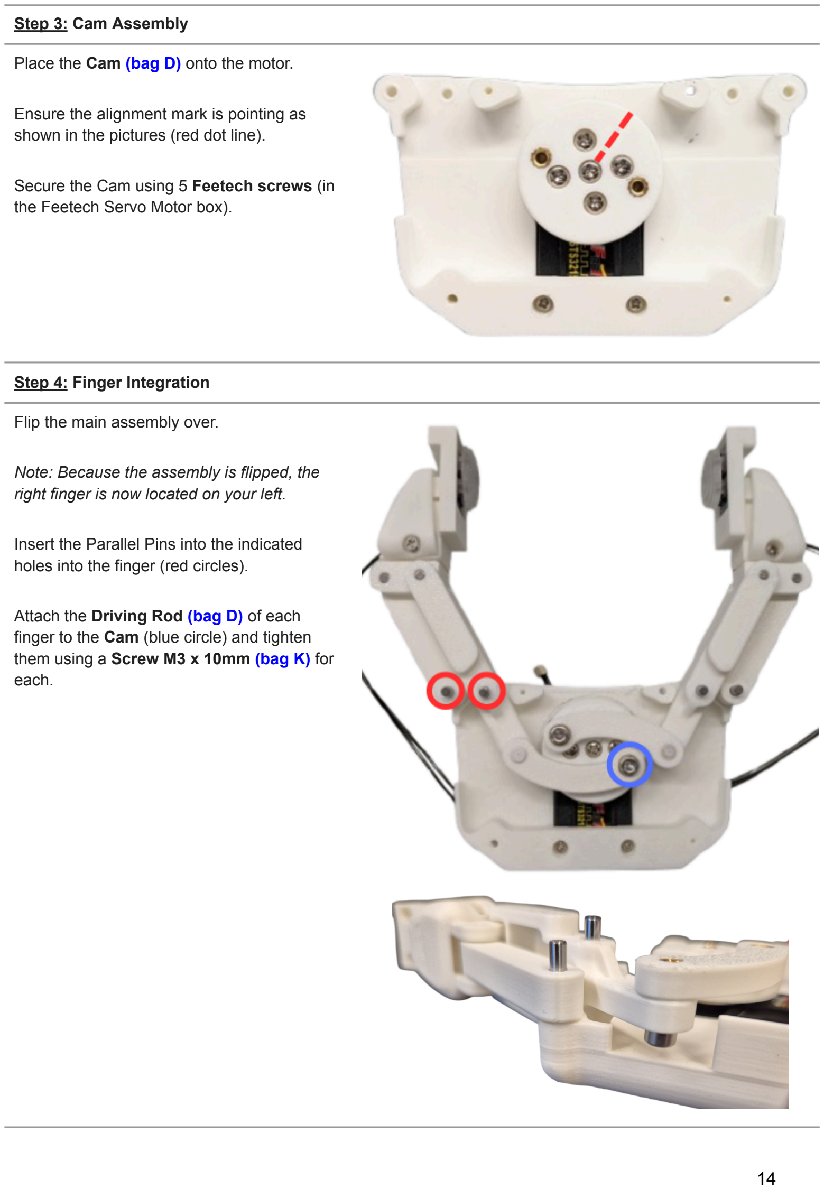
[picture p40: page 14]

Step 3: Cam Assembly

Place the Cam (bag D) onto the motor.

Ensure the alignment mark is pointing as shown in the pictures (red dot line).

Secure the Cam using 5 Feetech screws (in the Feetech Servo Motor box).

Step 4: Finger Integration

Flip the main assembly over.

Note: Because the assembly is flipped, the right finger is now located on your left.

Insert the Parallel Pins into the indicated holes into the finger (red circles).

Attach the Driving Rod (bag D) of each finger to the Cam (blue circle) and tighten them using a Screw M3 x 10mm (bag K) for each.

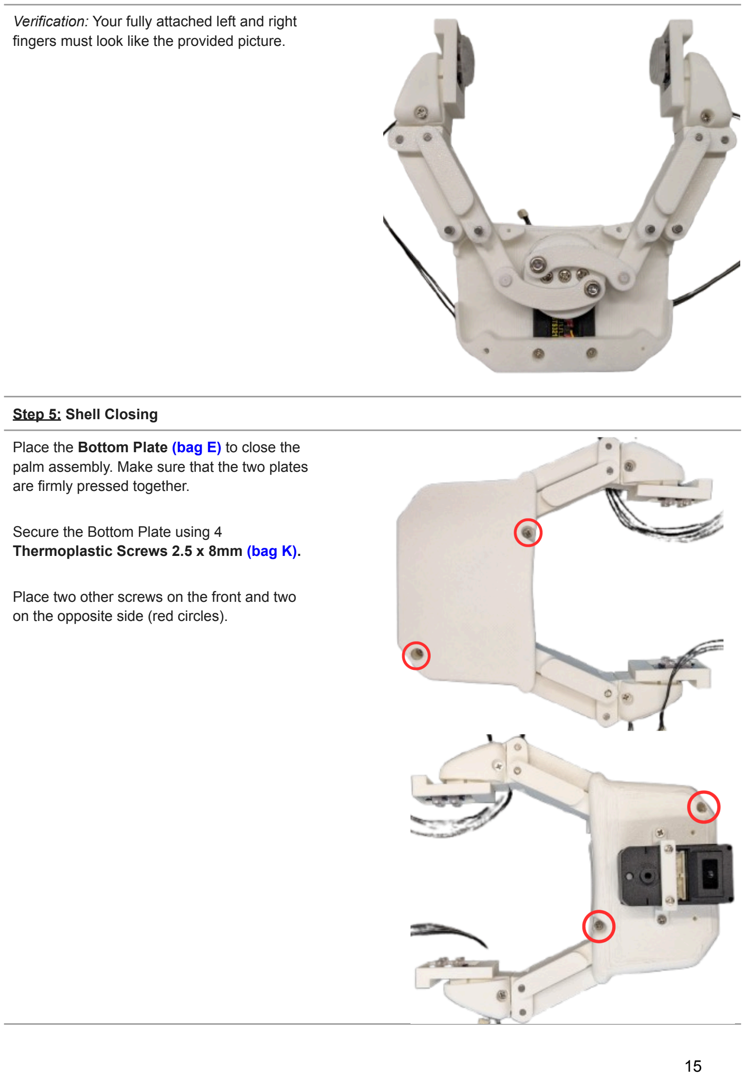
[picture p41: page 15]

Verification: Your fully attached left and right fingers must look like the provided picture.

Step 5: Shell Closing

Place the Bottom Plate (bag E) to close the palm assembly. Make sure that the two plates are firmly pressed together.

Secure the Bottom Plate using 4 Thermoplastic Screws 2.5 x 8mm (bag K).

Place two other screws on the front and two on the opposite side (red circles).

Step 6: Head Housing and PCBs

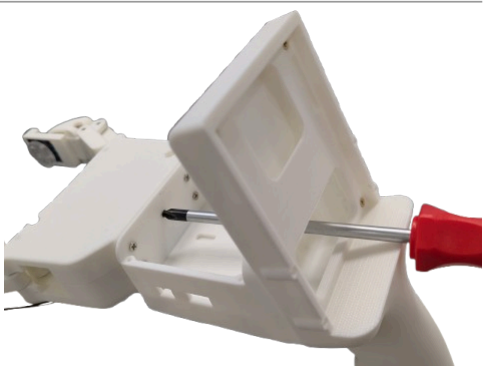
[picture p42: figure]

Attach the Head Housing support to the newly assembled hand. To do so, use five Thermoplastic Screw 2.5 × 8mm (bag K) and insert the screwdriver through the opening visible in the picture.

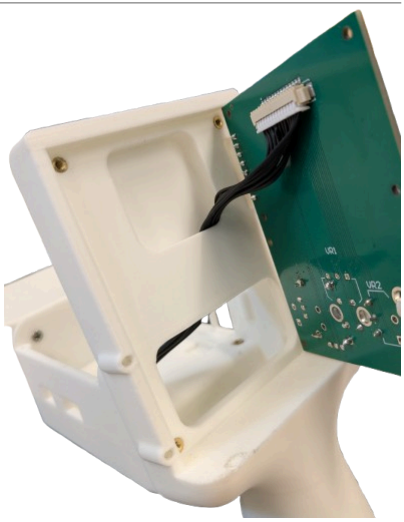
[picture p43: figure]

Position the PCB interface (bag H) and run the cable through the slot on the back as shown in the image.

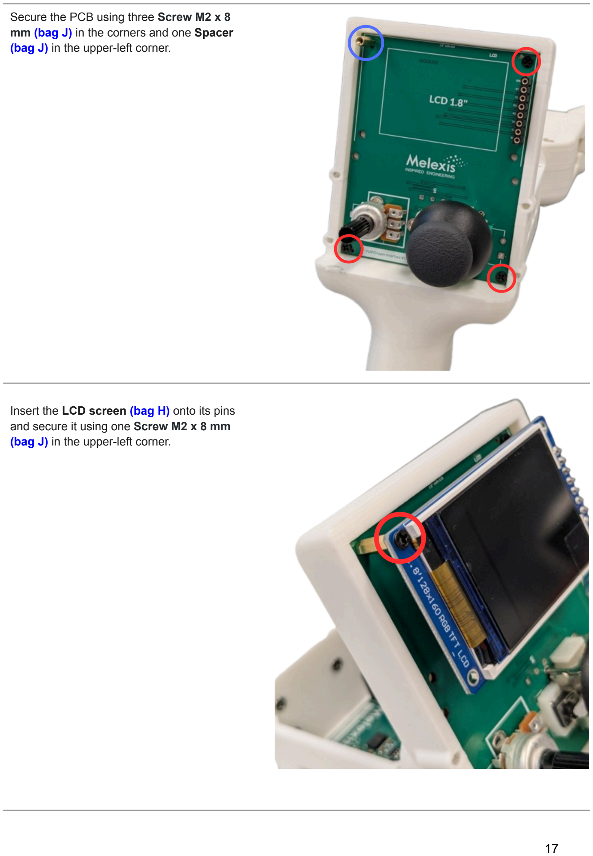
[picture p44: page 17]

Secure the PCB using three Screw M2 x 8 mm (bag J) in the corners and one Spacer (bag J) in the upper-left corner.

Insert the LCD screen (bag H) onto its pins and secure it using one Screw M2 x 8 mm (bag J) in the upper-left corner.

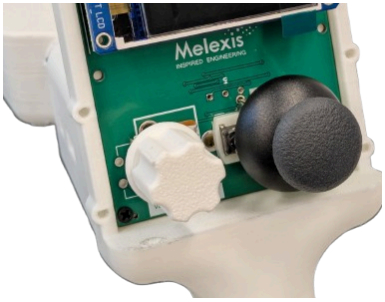
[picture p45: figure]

You can then place the Knob (bag F) onto the potentiometer and the Joystick Hat (bag
H) if it’s not already done.

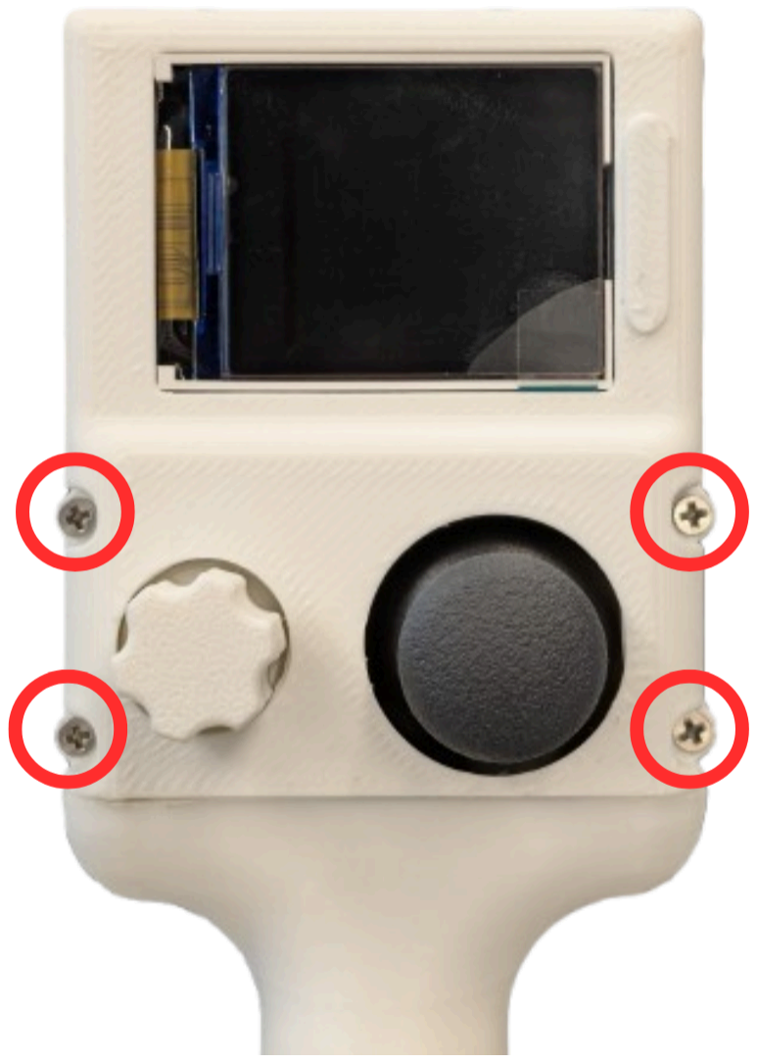
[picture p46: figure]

Install the Interface Panel (bag F) and secure it with four Thermoplastic Screw 2.5 × 8mm (bag K).

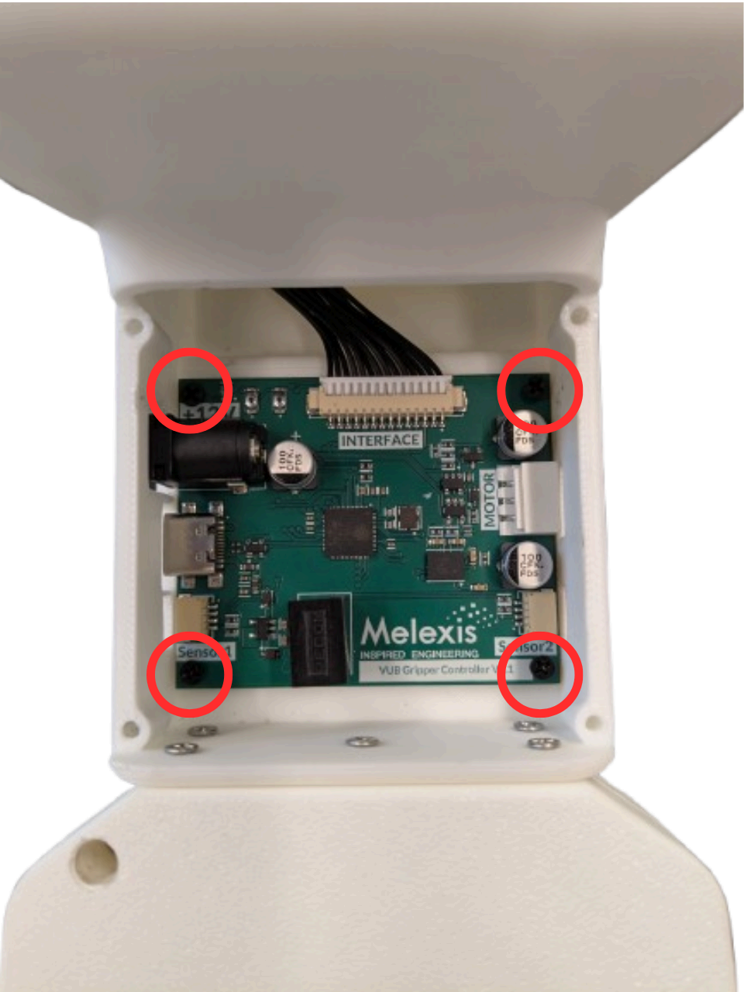
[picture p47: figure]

Insert the Controller PCB (bag I) into this slot.

To do so, slightly tilt the PCB so the power supply connector enters first.

Connect the black cable from the Interface PCB.

Then, secure the PCB using four Screw M2 x 8 mm (bag J).

There is no need to overtighten, the PCB only needs to remain stable.

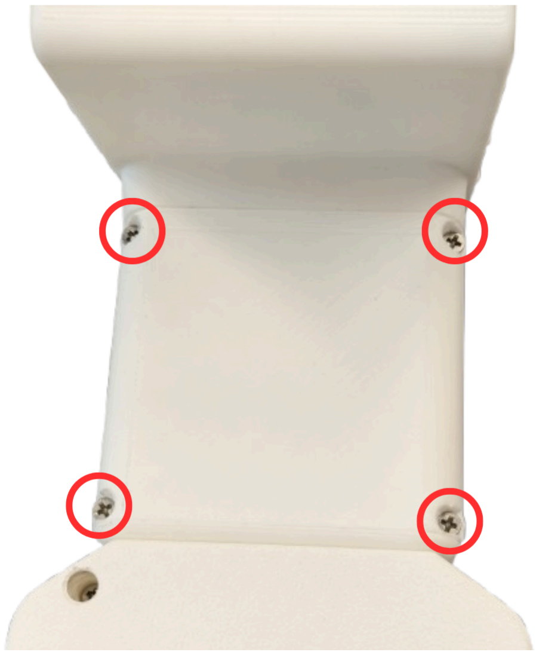
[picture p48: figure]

Install the Top Panel (bag F) using four Thermoplastic Screw 2.5 × 8mm (bag K).

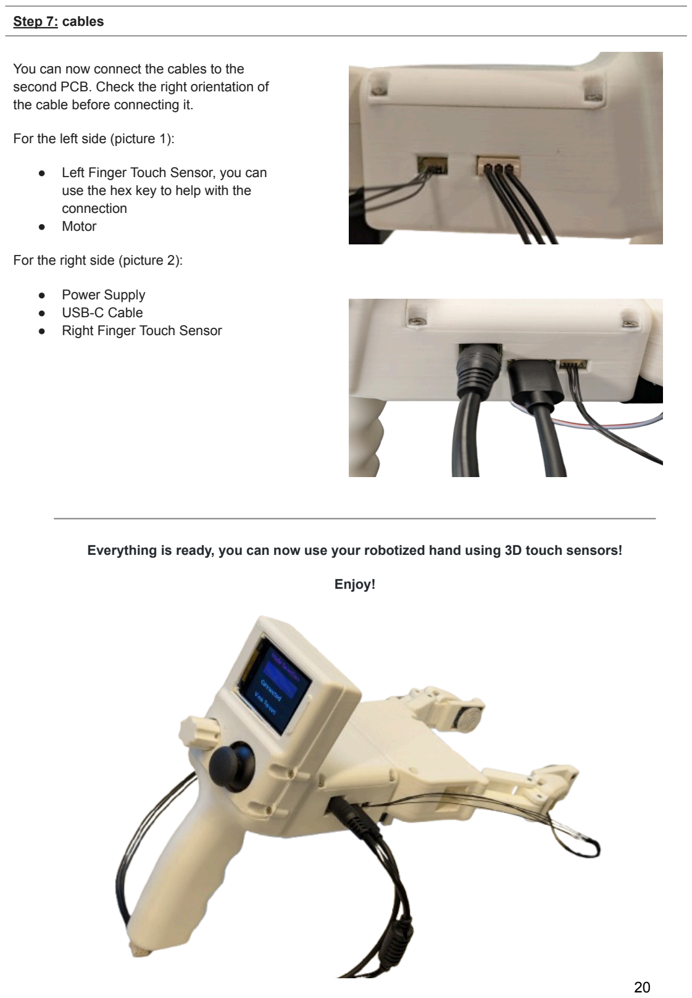
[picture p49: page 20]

Step 7: cables

You can now connect the cables to the second PCB. Check the right orientation of the cable before connecting it.

For the left side (picture 1):

- Left Finger Touch Sensor, you can use the hex key to help with the connection
- Motor

For the right side (picture 2):

- Power Supply
- USB-C Cable
- Right Finger Touch Sensor

Everything is ready, you can now use your robotized hand using 3D touch sensors!

Enjoy!

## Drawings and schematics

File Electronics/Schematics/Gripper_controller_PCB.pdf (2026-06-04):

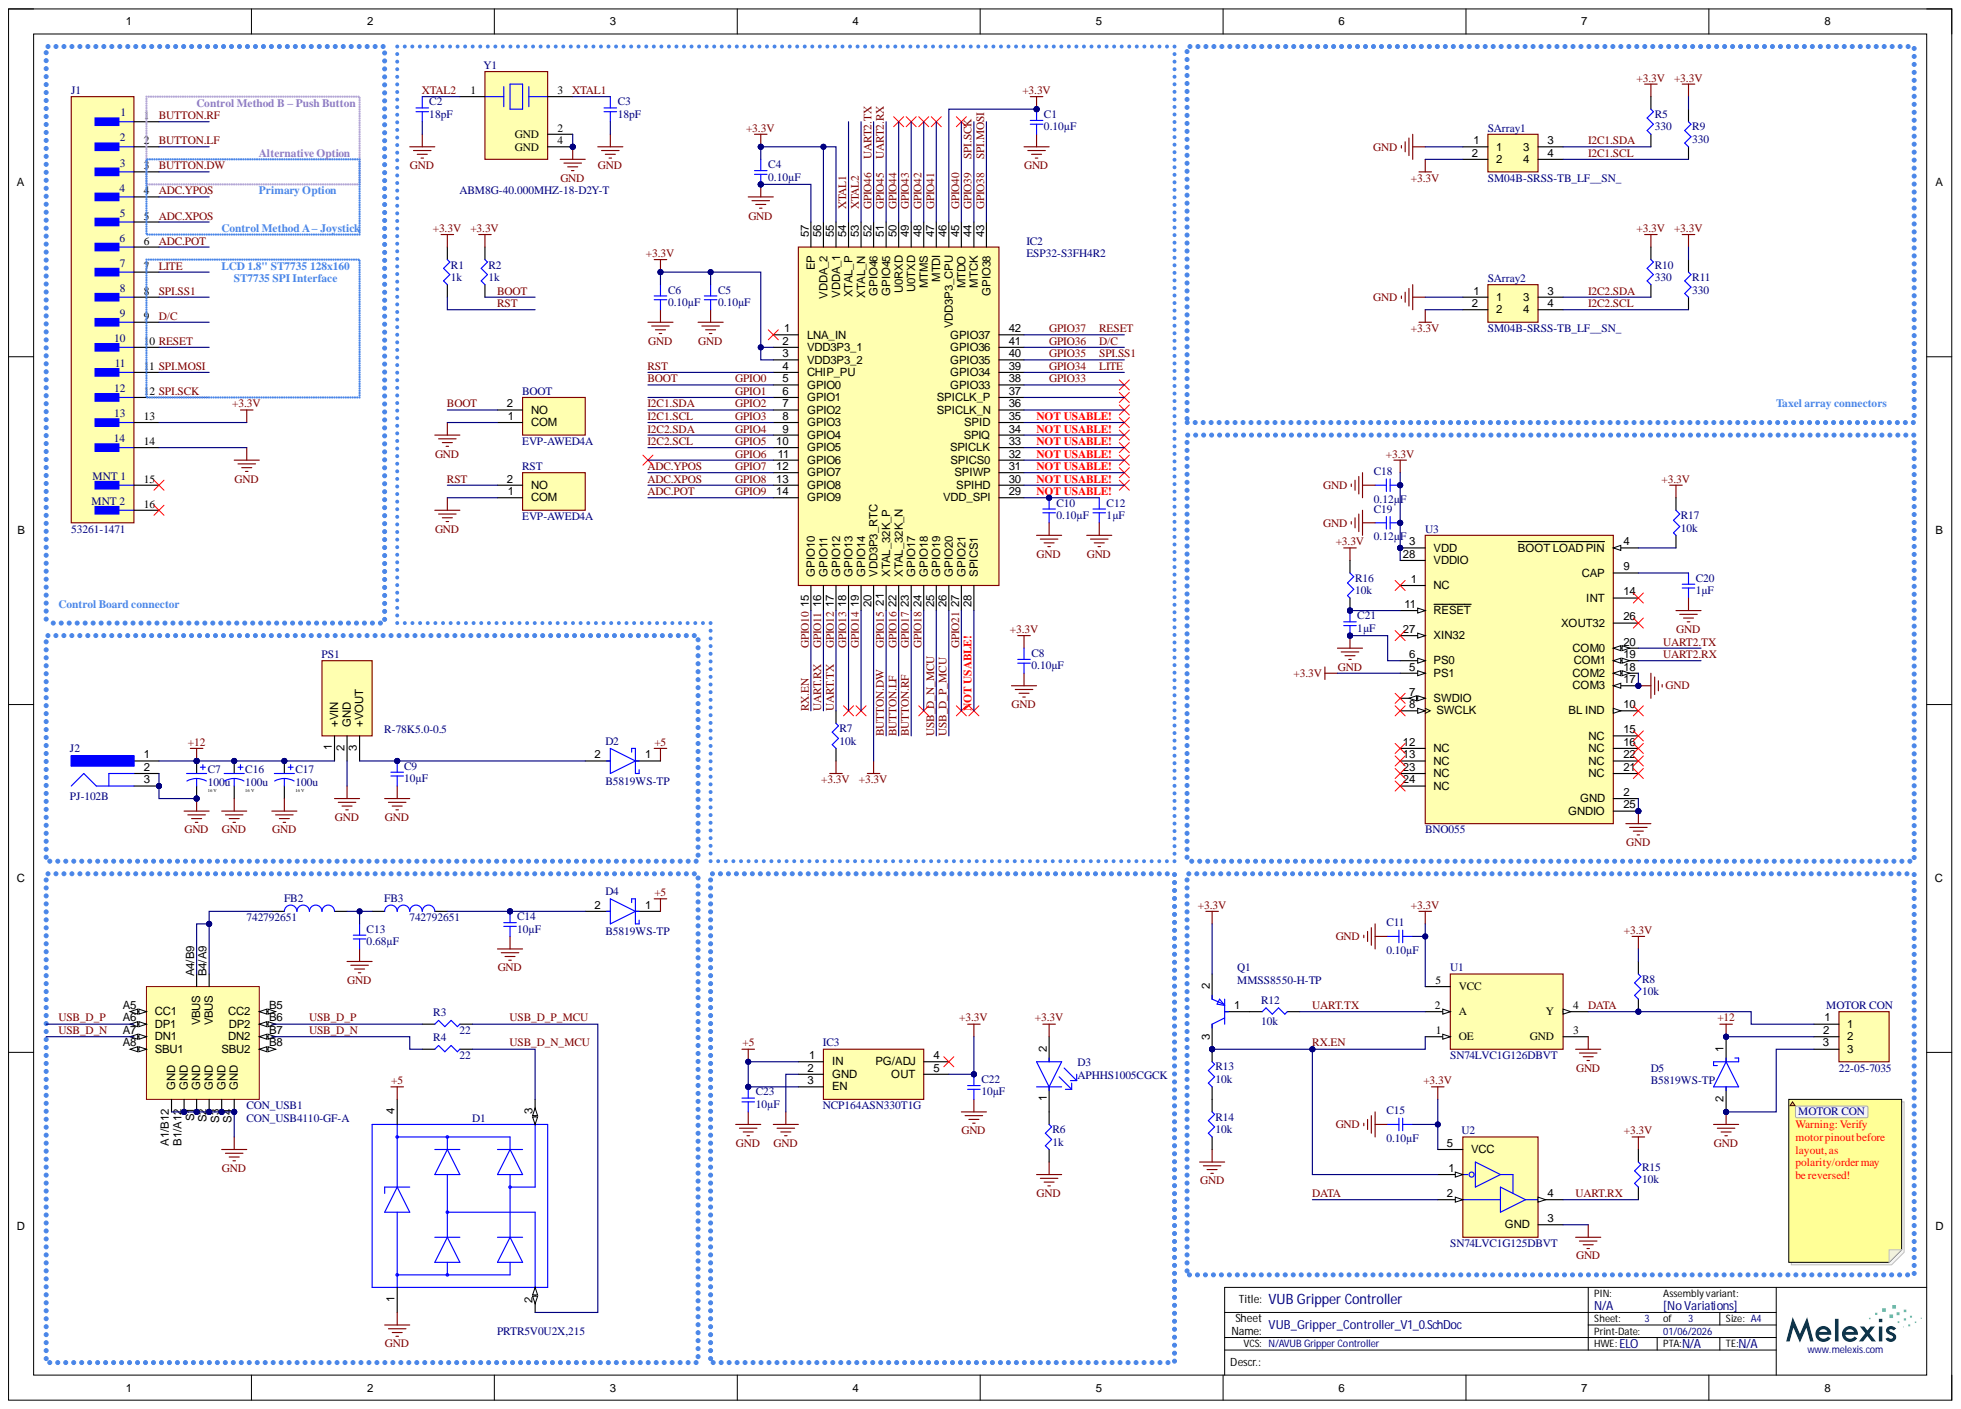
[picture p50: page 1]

Control Method B – Push Button

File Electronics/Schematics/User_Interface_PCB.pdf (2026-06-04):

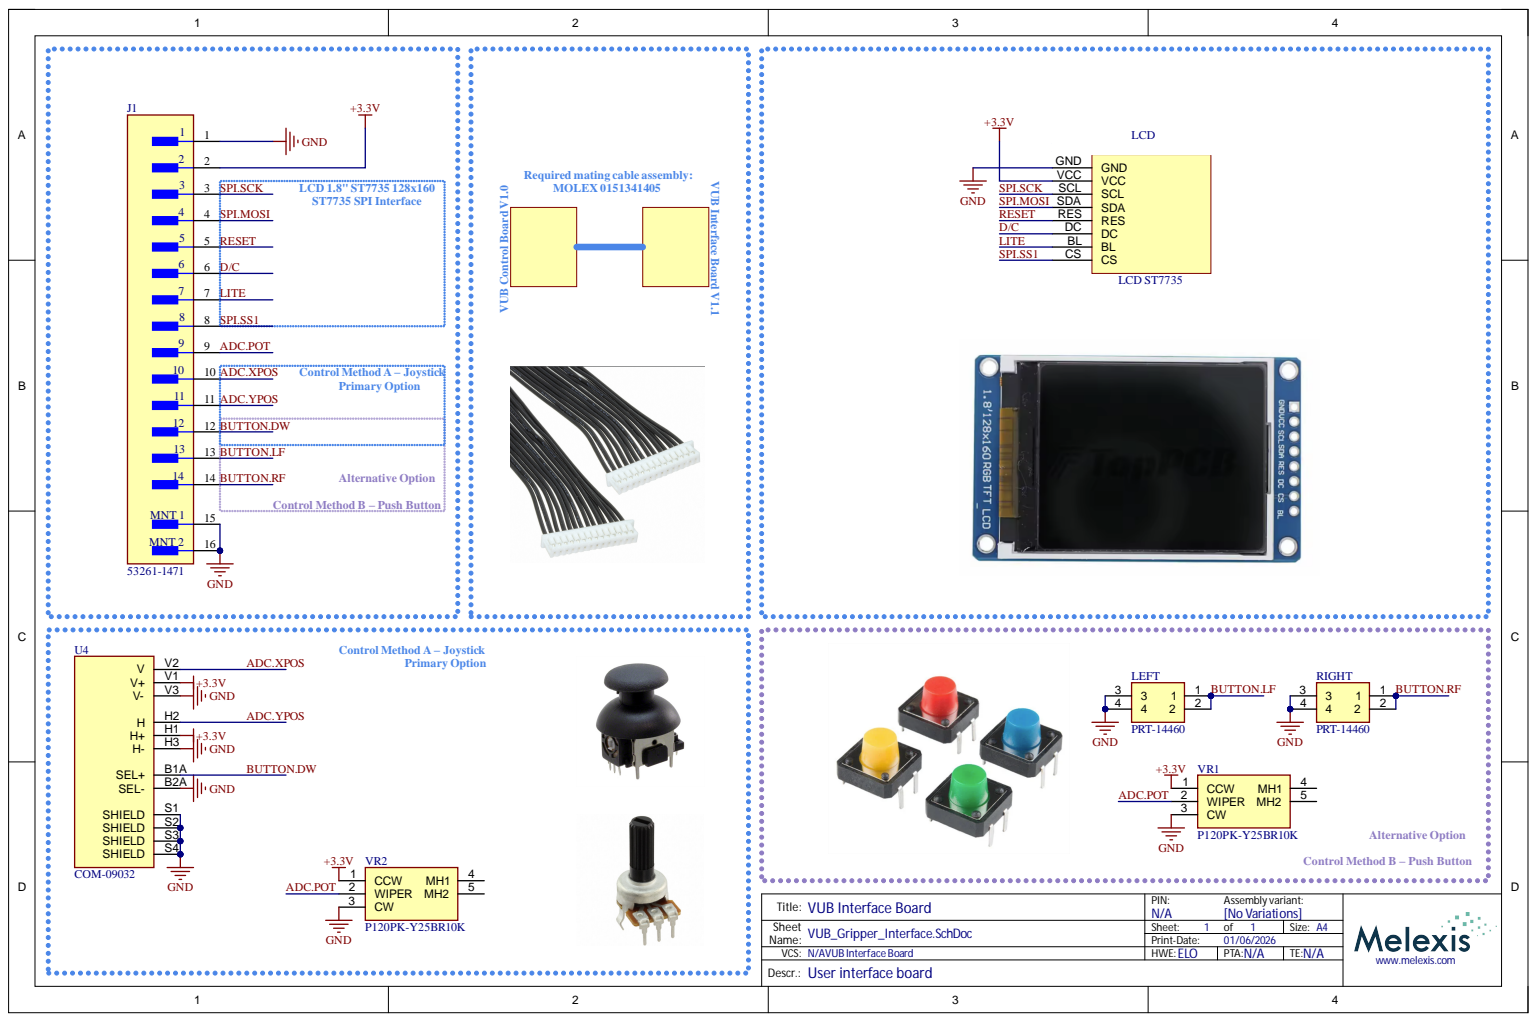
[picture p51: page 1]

Required mating cable assembly:
MOLEX 0151341405

Control Method B – Push Button

VUB Interface Board
Title:
Sheet
VUB_Gripper_Interface.SchDoc
VCS: N/AVUB Interface Board
User interface board

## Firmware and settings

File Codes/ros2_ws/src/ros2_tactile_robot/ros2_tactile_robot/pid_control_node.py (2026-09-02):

"""
Adaptive force controller with firmware-matched control structure.

Potentiometer sets target normal force (0–5 N).

Reference gain values for the three test objects :
  CUBE   → Kp=11  Kd=25  alpha=0.70  deadband=0.20 N
  SPONGE → Kp=20  Kd=28  alpha=0.75  deadband=0.15 N
  CUP    → Kp=28  Kd=35  alpha=0.80  deadband=0.10 N

Subscribers:
  /esp/force            std_msgs/Float32MultiArray  (24 floats: Fx0,Fy0,Fz0,...)
  /esp/imu              sensor_msgs/Imu             (gravity vector in m/s²)
  /esp/potentiometer    std_msgs/Int32
  /esp/motor_position   std_msgs/Int32
  /pid/gains            std_msgs/Float32MultiArray  ([kp, ki, kd])
  /pid/tare             std_msgs/Bool               (any message → zero fn and fg offsets)

Publishers:
  /motor/command        std_msgs/Float32MultiArray  ([position, speed, acc])
  /pid/state            std_msgs/Float32MultiArray
        [target_force, filtered_force, error, integral, derivative, pid_output, fg_fn_ratio]
  /pid/slip             std_msgs/Float32MultiArray
        [fg_fn_ratio, fg, fn]  (filtered, offset-corrected)
"""

import math

import rclpy
from rclpy.node import Node
from sensor_msgs.msg import Imu
from std_msgs.msg import Bool, Float32MultiArray, Int32

_FORCE_MAX   = 5.0     # N — full potentiometer deflection
_POT_MAX     = 4095
_MOTOR_MIN   = 1500
_MOTOR_MAX   = 2800
_MOTOR_SPEED = 300     

_MIN_TARGET  = 0.1     # N — below this the controller is inhibited (gripper idle)

_N_WARMUP    = 50      # samples discarded so the filter + IMU stream settle first
_N_CALIB     = 20      # samples averaged for the startup auto-zero baseline


class PidControlNode(Node):
    def __init__(self):
        super().__init__('pid_control_node')

        self.declare_parameter('kp',             0.0)
        self.declare_parameter('ki',             0.0)
        self.declare_parameter('kd',             0.0)
        self.declare_parameter('alpha',          0.75)   # LPF weight for fn/fg (0=frozen, 1=raw)
        self.declare_parameter('alpha_ratio',    0.30)   # LPF weight for the Fg/Fn ratio
        self.declare_parameter('deadband_n',     0.15)   # N — error deadband
        self.declare_parameter('motor_acc',      200)
        self.declare_parameter('enabled',        True)

        self._kp             = self.get_parameter('kp').value
        self._ki             = self.get_parameter('ki').value
        self._kd             = self.get_parameter('kd').value
        self._alpha          = float(self.get_parameter('alpha').value)
        self._alpha_ratio    = float(self.get_parameter('alpha_ratio').value)
        self._deadband       = float(self.get_parameter('deadband_n').value)
        self._motor_acc      = self.get_parameter('motor_acc').value
        self._enabled        = self.get_parameter('enabled').value

        if self._kp == 0.0 and self._ki == 0.0 and self._kd == 0.0:
            self.get_logger().warn(
                'kp, ki and kd are all 0.0 (the launch-file default) — the '
                'controller will compute zero correction and the motor will not '
                'move. Pass kp:=/ki:=/kd:= on the command line, e.g. '
                "'ros2 launch ros2_tactile_robot pid_force_control.launch.py "
                "kp:=11 kd:=25' — see the reference gain table in Codes/README.md."
            )

        self._filtered_force  = 0.0
        self._filtered_fg     = 0.0
        self._filtered_ratio  = 0.0
        self._prev_dif_force  = 0.0
        self._integral_error  = 0.0
        self._offset_fn       = 0.0
        self._offset_fg       = 0.0
        self._last_fn_raw     = 0.0
        self._last_fg_raw     = 0.0

        self._offset_ready    = False
        self._calib_count     = 0
        self._calib_fn: list[float] = []
        self._calib_fg: list[float] = []

        self._pot_value: int   | None = None
        self._motor_pos: int   | None = None
        self._gravity:   tuple | None = None

        self._pub_motor = self.create_publisher(Float32MultiArray, '/motor/command', 10)
        self._pub_state = self.create_publisher(Float32MultiArray, '/pid/state',     10)
        self._pub_slip  = self.create_publisher(Float32MultiArray, '/pid/slip',      10)

        self.create_subscription(Float32MultiArray, '/esp/force',
                                 self._on_force,     10)
        self.create_subscription(Imu,               '/esp/imu',
                                 self._on_imu,       10)
        self.create_subscription(Int32,             '/esp/potentiometer',
                                 self._on_pot,       10)
        self.create_subscription(Int32,             '/esp/motor_position',
                                 self._on_motor_pos, 10)
        self.create_subscription(Float32MultiArray, '/pid/gains',
                                 self._on_gains,     10)
        self.create_subscription(Bool,              '/pid/tare',
                                 self._on_tare,      10)



    def _on_tare(self, _msg: Bool):
        self._offset_fn      = self._last_fn_raw
        self._offset_fg      = self._last_fg_raw
        self._offset_ready   = True
        self._filtered_force = 0.0
        self._filtered_fg    = 0.0
        self._filtered_ratio = 0.0
        self._integral_error = 0.0
        self._prev_dif_force = 0.0
        self.get_logger().info(
            f'PID tare applied: fn offset = {self._offset_fn:.3f} N  '
            f'fg offset = {self._offset_fg:.3f} N')

    def _on_gains(self, msg: Float32MultiArray):
        if len(msg.data) >= 3:
            self._kp, self._ki, self._kd = (
                float(msg.data[0]), float(msg.data[1]), float(msg.data[2]))
            self._integral_error = 0.0
            self.get_logger().info(
                f'Gains updated: Kp={self._kp}  Ki={self._ki}  Kd={self._kd}')

    def _on_pot(self, msg: Int32):
        self._pot_value = msg.data

    def _on_motor_pos(self, msg: Int32):
        self._motor_pos = msg.data

    def _on_imu(self, msg: Imu):
        self._gravity = (
            msg.linear_acceleration.x,
            msg.linear_acceleration.y,
            msg.linear_acceleration.z,
        )

    def _on_force(self, msg: Float32MultiArray):
        data = msg.data
        if len(data) < 24:
            return

        s = [[float(data[i*3]), float(data[i*3+1]), float(data[i*3+2])]
             for i in range(8)]
        lF, rF = s[:4], s[4:]

        fx_L = sum(v[0] for v in lF)
        fy_L = sum(v[1] for v in lF)
        fz_L = sum(v[2] for v in lF)
        fx_R = sum(v[0] for v in rF)
        fy_R = sum(v[1] for v in rF)
        fz_R = sum(v[2] for v in rF)

        fx_tot = fx_L + fx_R
        fy_tot = fy_L - fy_R
        fz_tot = fz_L - fz_R

        self._last_fn_raw = -(fz_L + fz_R)

        # Gravity-aligned shear force fg
        if self._gravity is not None:
            gx, gy, gz = self._gravity
            g_mag = math.sqrt(gx*gx + gy*gy + gz*gz)
            # Firmware axis mapping: Fx·gx + Fy·gz + Fz·gy (sensor y/z swapped vs IMU)
            fg_raw = ((fx_tot*gx + fy_tot*gz + fz_tot*gy) / g_mag
                      if g_mag > 1e-6 else 0.0)
        else:
            g_mag  = 0.0
            fg_raw = math.sqrt(fx_tot**2 + fy_tot**2)
        self._last_fg_raw = fg_raw

        # Auto-zero baseline offsets when the gripper is not in contact
        if not self._offset_ready:
            self._calib_count += 1
            if self._calib_count <= _N_WARMUP or g_mag <= 1e-6:
                return
            self._calib_fn.append(self._last_fn_raw)
            self._calib_fg.append(self._last_fg_raw)
            if len(self._calib_fn) < _N_CALIB:
                return
            self._offset_fn    = sum(self._calib_fn) / len(self._calib_fn)
            self._offset_fg    = sum(self._calib_fg) / len(self._calib_fg)
            self._offset_ready = True
            self.get_logger().info(
                f'Auto-zero: fn offset = {self._offset_fn:.3f} N  '
                f'fg offset = {self._offset_fg:.3f} N '
                f'(averaged {len(self._calib_fn)} samples)')

        fn = self._last_fn_raw - self._offset_fn
        fg = fg_raw - self._offset_fg

        # Smooth fn and fg
        self._filtered_force = (self._alpha * fn
                                + (1.0 - self._alpha) * self._filtered_force)
        self._filtered_fg    = (self._alpha * fg
                                + (1.0 - self._alpha) * self._filtered_fg)

        ratio_inst = (self._filtered_fg / self._filtered_force
                      if abs(self._filtered_force) > 1e-6 else 0.0)
        self._filtered_ratio = (self._alpha_ratio * ratio_inst
                                + (1.0 - self._alpha_ratio) * self._filtered_ratio)
        ratio = self._filtered_ratio

        slip_msg = Float32MultiArray()
        slip_msg.data = [float(ratio), float(self._filtered_fg),
                         float(self._filtered_force)]
        self._pub_slip.publish(slip_msg)

        if not self._enabled or self._pot_value is None or self._motor_pos is None:
            return

        target_force = (self._pot_value / _POT_MAX) * _FORCE_MAX

        if target_force < _MIN_TARGET:
            self._integral_error = 0.0
            self._prev_dif_force = 0.0
            # Open the gripper so no residual force is held at 0 N target
            if self._motor_pos > _MOTOR_MIN:
                cmd = Float32MultiArray()
                cmd.data = [float(_MOTOR_MIN), float(_MOTOR_SPEED), float(self._motor_acc)]
                self._pub_motor.publish(cmd)
            return

        dif_force = target_force - self._filtered_force
        d_force   = dif_force - self._prev_dif_force
        self._prev_dif_force = dif_force

        if self._ki != 0.0:
            self._integral_error += dif_force

        correction = int(dif_force * self._kp
                         + self._integral_error * self._ki
                         + d_force * self._kd)

        send_cmd = False
        new_pos  = self._motor_pos

        if dif_force < -self._deadband:
            candidate = self._motor_pos + correction
            if candidate >= _MOTOR_MIN:
                new_pos  = candidate
                send_cmd = True
        elif dif_force > self._deadband:
            candidate = self._motor_pos + correction
            if candidate <= _MOTOR_MAX:
                new_pos  = candidate
                send_cmd = True

        if send_cmd:
            new_pos = max(_MOTOR_MIN, min(_MOTOR_MAX, new_pos))
            cmd = Float32MultiArray()
            cmd.data = [float(new_pos), float(_MOTOR_SPEED), float(self._motor_acc)]
            self._pub_motor.publish(cmd)

        state_msg = Float32MultiArray()
        state_msg.data = [
            float(target_force),
            float(self._filtered_force),
            float(dif_force),
            float(self._integral_error),
            float(d_force),
            float(correction),
            float(ratio),
        ]
        self._pub_state.publish(state_msg)


def main(args=None):
    rclpy.init(args=args)
    node = PidControlNode()
    try:
        rclpy.spin(node)
    except KeyboardInterrupt:
        pass
    finally:
        node.destroy_node()
        rclpy.shutdown()


if __name__ == '__main__':
    main()

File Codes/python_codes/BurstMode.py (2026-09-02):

import csv
import math
import time
import sys
import threading
import argparse
from collections import deque
from pathlib import Path

# Make project-root imports work
ROOT_DIR = Path(__file__).resolve().parents[2]
if str(ROOT_DIR) not in sys.path:
    sys.path.insert(0, str(ROOT_DIR))

from SerialLibrary.lib_esp32 import espDriver

_MOTOR_MIN = 1500   # minimum motor position when driven by potentiometer
_MOTOR_MAX = 2800   # maximum motor position when driven by potentiometer
_SIN45     = math.sin(math.radians(45))

_RECORD_DIR = Path(__file__).resolve().parents[1] / 'record_data'
_RECORD_DIR.mkdir(exist_ok=True)


_MOTOR_DEBOUNCE_LSB = 5


def parse_args() -> argparse.Namespace:
    parser = argparse.ArgumentParser(description="Burst-mode live GUI.")
    parser.add_argument("-p", "--com-port", default=None,
                        help="Serial COM port (default: auto-detect ESP32-S3).")
    parser.add_argument("-g", "--debug", action="store_true",
                        help="Print each received frame as-is before decoding.")
    parser.add_argument("--no-motor-pot", action="store_true",
                        help="Disable automatic motor commands derived from the potentiometer.")
    parser.add_argument("--shear-scale", type=float, default=2.0,
                        help="Shear force (Fx, Fy) at full bar deflection, in each "
                             "direction (default: 2.0 N).")
    parser.add_argument("--normal-scale", type=float, default=5.0,
                        help="Normal force (Fz) at full bar deflection, in each "
                             "direction (default: 5.0 N).")
    parser.add_argument("--poll-ms", type=int, default=50,
                        help="GUI refresh interval in milliseconds (default: 50).")
    return parser.parse_args()


# GUI

class BurstModeGui:
    """Live visualization GUI for the burst-force stream.

    Panels
    ------
    - Force bars  : one group of 3 bars (Fx/Fy/Fz) per sensor (S0–S7).
    - Joystick    : dot on a pad circle; red = released, green = pressed.
    - Potentiometer: rotating knob, 0–4095 mapped to 0–360°.
    - Motor       : rotating needle on a motor diagram, 0–4095 → 0–360°.
    - IMU         : isometric 3-D arrow for the BNO055 gravity vector.
    """

    # Colours (Catppuccin Mocha palette) 
    _BG        = "#1e1e2e"
    _SURFACE   = "#181825"
    _SURFACE1  = "#313244"
    _OVERLAY   = "#45475a"
    _TEXT      = "#cdd6f4"
    _SUBTEXT   = "#6c7086"
    _RED       = "#e63946"
    _TEAL      = "#2a9d8f"
    _BLUE      = "#89b4fa"
    _PINK      = "#f38ba8"
    _YELLOW    = "#f9e2af"
    _GREEN     = "#a6e3a1"
    _FX_COL    = "#e63946"
    _FY_COL    = "#2a9d8f"
    _FZ_COL    = "#457b9d"

    _N_SENSORS    = 8
    _GRAVITY_NORM = 981   # LSB for 1 g  (BNO055 gravity in units of 1/100 m/s²)
    _JOY_HALF     = 2048  # joystick half-range

    def __init__(
        self,
        esp: "espDriver",
        poll_ms: int = 50,
        shear_scale: float = 2.0,
        normal_scale: float = 5.0,
        no_motor_pot: bool = False,
        motor_debounce: int = _MOTOR_DEBOUNCE_LSB,
    ) -> None:
        import tkinter as tk
        self._tk = tk

        self._esp = esp
        self._poll_ms = max(10, poll_ms)
        # Full-scale deflection per axis, in each direction: shear on Fx/Fy, normal on Fz. 
        self._axis_scale = (max(0.1, shear_scale),
                            max(0.1, shear_scale),
                            max(0.1, normal_scale))
        self._no_motor_pot = no_motor_pot
        self._motor_debounce = motor_debounce
        self._last_motor_cmd_pot: int | None = None

        self._running = False
        self._last_rate_t = time.time()
        self._last_sample_count = esp.sample_counter

        self._root = tk.Tk()
        self._root.title("Burst Mode  —  Live Visualizer")
        self._root.resizable(False, False)
        self._root.configure(bg=self._BG)

        self._build_header()
        self._build_force_panel()
        self._build_peripheral_row()
        self._build_status_bar()

        self._root.protocol("WM_DELETE_WINDOW", self._on_close)

        self._lock = threading.Lock()
        self._recording: deque = deque()
        self._is_recording = False
        self._rec_t0: float | None = None
        self._tare_offsets = [[0.0, 0.0, 0.0] for _ in range(self._N_SENSORS)]

        # Two-stage LPF for Fn/Fg/ratio
        self._lpf_alpha       = 0.75
        self._lpf_alpha_ratio = 0.30
        self._filtered_fn     = 0.0
        self._filtered_fg     = 0.0
        self._filtered_ratio  = 0.0
        self._lpf_seeded      = False

        # Rolling-window peak-to-peak amplitude of the Fg/Fn ratio 
        self._ratio_window_size          = 20
        self._ratio_window: deque[float] = deque(maxlen=self._ratio_window_size)
        self._ratio_amp                  = 0.0
        self._amp_alpha                  = 1.0

        self._build_record_bar()

    # Layout builders

    def _build_header(self) -> None:
        tk = self._tk
        row = tk.Frame(self._root, bg=self._BG)
        row.pack(fill="x", padx=12, pady=(10, 4))

        self._sample_var = tk.StringVar(value="Sample: 0")
        self._rate_var   = tk.StringVar(value="Rate: — Hz")

        tk.Label(row, textvariable=self._sample_var, bg=self._BG,
                 fg=self._TEXT, font=("Segoe UI", 10)).pack(side="left")
        tk.Label(row, textvariable=self._rate_var, bg=self._BG,
                 fg=self._TEXT, font=("Segoe UI", 10)).pack(side="right")

    def _build_force_panel(self) -> None:
        tk = self._tk

        # Canvas dimensions
        self._fc_col_w  = 136
        self._fc_bar_h  = 26
        self._fc_margin = 5
        self._fc_w = self._N_SENSORS * self._fc_col_w
        self._fc_h = 3 * (self._fc_bar_h + self._fc_margin) + 32  # 32 for sensor label

        outer = tk.LabelFrame(
            self._root, text="Force Sensors", padx=6, pady=4,
            bg=self._BG, fg=self._TEXT, font=("Segoe UI", 9, "bold"), bd=1,
        )
        outer.pack(padx=12, pady=(0, 6), fill="x")

        c = tk.Canvas(outer, width=self._fc_w, height=self._fc_h,
                      bg=self._SURFACE, highlightthickness=0)
        c.pack()
        self._fc = c

        # Static backgrounds + axis labels 
        self._bar_ids: list[list[int]] = []   # [sensor][axis] → bar canvas id
        self._val_ids: list[list[int]] = []   # [sensor][axis] → value text id

        # Bars are unidirectional (|force|), filling left-to-right.
        # Layout per column: axis label (18 px) | track (col_w - 22 px) | value (right-anchored)
        self._fc_bar_x_off = 20   # px from column left where bar fill starts
        self._fc_bar_max_w = self._fc_col_w - 24  # max fill width in px

        for s in range(self._N_SENSORS):
            x0     = s * self._fc_col_w
            col_cx = x0 + self._fc_col_w // 2
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

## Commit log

2026-06-04 Repository for partipants
    [BOM.xlsx, Distal_Shell.STEP, Distal_Shell.STL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]
2026-08-24 V2 of the tutorial
    [BOM.xlsx, Gripper - BOM.xlsx, Tactaxis_PDMS_Cover.STEP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]
2026-08-24 Update motor initialisation position
2026-09-02 Small changes
    [Interface_Panel.STL]
2026-09-02 Changed STL name
    [Tactaxis_Sensor.STEP, Tactaxis_Sensor.STL]
